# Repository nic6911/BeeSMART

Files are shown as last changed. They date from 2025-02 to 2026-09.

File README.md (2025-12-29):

# BeeSMART

If you like then please

"Buy Me A Coffee" (https://bmc.link/nic6911w)

This work is licensed under a  
[Creative Commons Attribution-NonCommercial-ShareAlike 4.0 International License][cc-by-nc-sa].

[][cc-by-nc-sa]

[cc-by-nc-sa]: http://creativecommons.org/licenses/by-nc-sa/4.0/  
[cc-by-nc-sa-image]: https://licensebuttons.net/l/by-nc-sa/4.0/88x31.png  
[cc-by-nc-sa-shield]: https://img.shields.io/badge/License-CC%20BY--NC--SA%204.0-lightgrey.svg

---

## Buy one, Køb en, Kaufen 
€200 + shipping from DK

Write me an email:

Contact

---

## What is it?
Honey filling system controlled from your phone, tablet or PC !

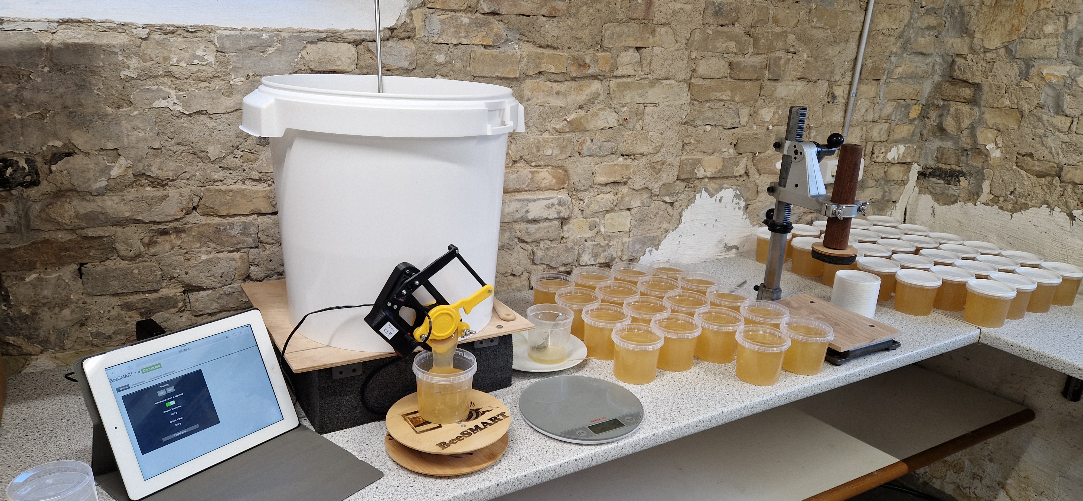
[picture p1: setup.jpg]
Setup
 

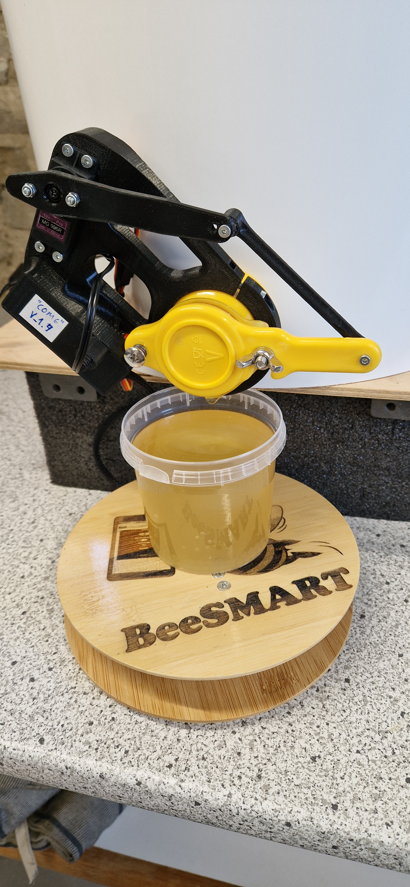
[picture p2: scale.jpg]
Scale
 

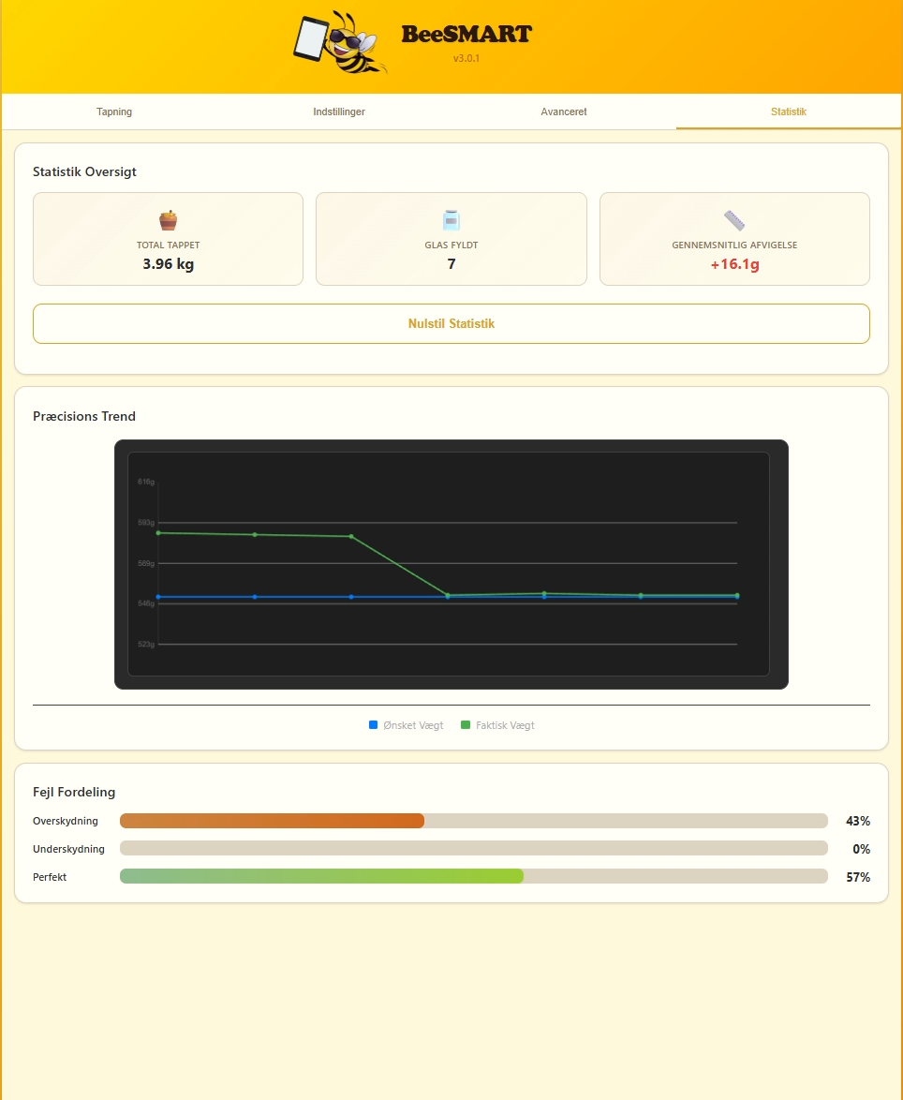
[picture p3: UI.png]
 

---

## Dansk
Honning tappemaskine til den lille produktion.
WIFI baseret med brugerinterface på pc, tablet eller smartphone uden en app.

### Video
Demo: https://youtu.be/7Y-k81tILdg
Montage: https://youtu.be/ojsv-gZ6waY

### Specs
Leverer inden for +/- 5g. Doseringsmængden kan indstilles mellem 50g og 20kg (Vær opmærksom på vægtens max belastning som kan være væsentligt mindre end 20kg !).
Se manual for funktionalitet: https://github.com/nic6911/BeeSMART/blob/develop/Documentation/manualDK.pdf

--- 

## Deutsch
Honig Abfüllsystem für den kleinen Produktion.
BeeSMART basiert sich auf WiFi und bietet eine Benutzeroberfläche 
entweder auf einem PC, Tablet oder Smartphone, ohne dass eine APP benötigt wird.

### Video
Demo: https://youtu.be/7Y-k81tILdg
Montage: https://youtu.be/ojsv-gZ6waY

### Specs
Es ist möglich mit einer Genauigkeit von +/- 5g zu erreichen. Der Menge kann zwischen 50g und 20kg eingestellt werden (Achte auf die maximale Belastung der Waage, die möglicherweise deutlich weniger als 20 kg beträgt !).
Für detaillierte Beschreibung von Funktionalität bitte lesen sie das Manual hier: https://github.com/nic6911/BeeSMART/blob/develop/Documentation/manualDE.pdf

---

## English
Honey filling machine for the small production.
WIFI based with user interface on pc, tablet or smartphone without the need for an app.

### Video
Demo: https://youtu.be/7Y-k81tILdg
Assembly: https://youtu.be/ojsv-gZ6waY

### Specs
An accuracy of +/- 5g is achievable. The amount to fill can be selected in the range from 50g to 20kg (Be mindful of the scale's maximum load, which may be significantly less than 20kg !).
See the user manual for more information: https://github.com/nic6911/BeeSMART/blob/develop/Documentation/manualEN.pdf

---

## Mechanical parts
Find the STL files for 3D printing in the STL's folder. The 2nd revision fits the updated hardware that is also found in the hardware folder.

## Hardware
The hardware is specifically designed for the project. RJ45 is utilized for connecting scale and mainboard, giving a seamless and robust connection. Power is provided from a 3A 5V USB-C power supply while the servo has its dedicated connector on the main board.
Schematic drawings, production files and source files are found under each subsystem folder in the Hardware folder (i.e. Scale and Mainboard).

### Mainboard
The mainboard contains the ESP32C3 and interfaces for programmin and power (USB-C), scale and servo as well as reset and boot buttons. The system is easily programmed using Arduino through the USB-C interface.

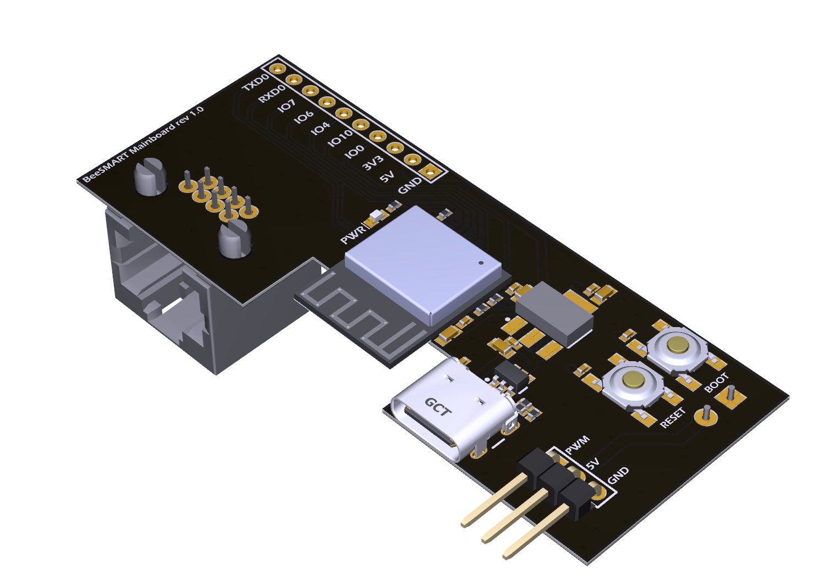
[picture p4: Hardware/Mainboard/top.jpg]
 

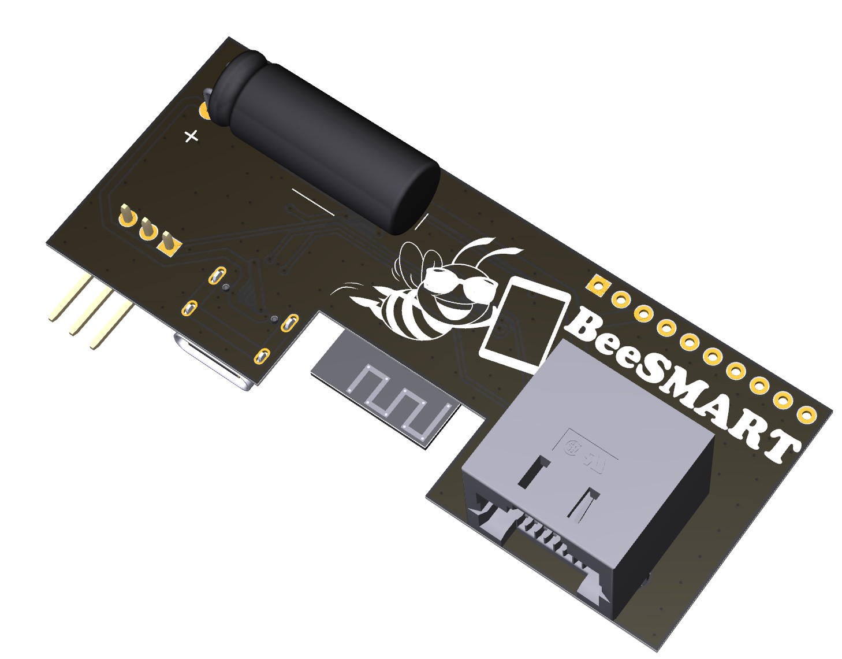
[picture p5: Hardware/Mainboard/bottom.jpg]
 

### Scale
The scale board contains an HX711 to interface with common load cells. No programming required - but calibration from the main controller is required at commissioning.

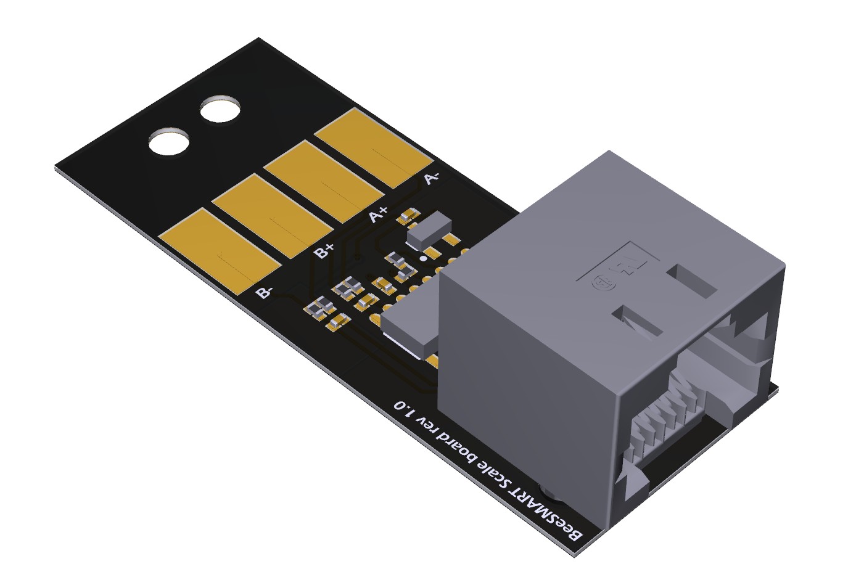
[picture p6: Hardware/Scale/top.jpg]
 

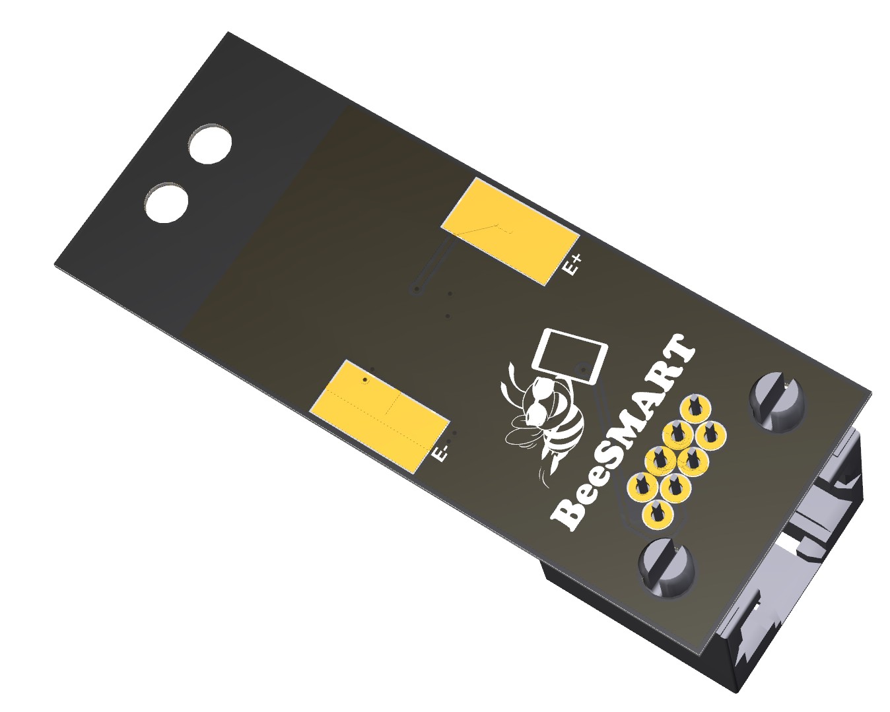
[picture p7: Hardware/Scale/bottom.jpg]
 

## Construction
There are a number of parts to acquire and some to 3D print. All the parts for printing are found in the Mechanical folder. You'll need one of each BUT only one of the brackets (either 40 or 53mm) and one of the main controller housing (40 or 53mm).

Besides the 3D printed parts some of the main components you'll need are:

- 2 x Ikea Bamboo lids Art no 103.819.09
- 1 x Standard size servo like e.g., MG996R
- 1 x Load cell
- 1 x Mainboard
- 1 x Scale board
- 1 x 5V 3A USB-C power supply
- 1 x RJ45 cable

The scale is constructed using two Ikea Bamboo lids Art no 103.819.09, the 3D printed encapsulation, electronics and a load cell that can be found almost anywhere. To assemble the scale, two holes must be drilled in each bamboo lid, where one side of the load cell is typically M4 and the other side M5. To mount them you'll need 2 x M4x25 and 2 x M5x30.

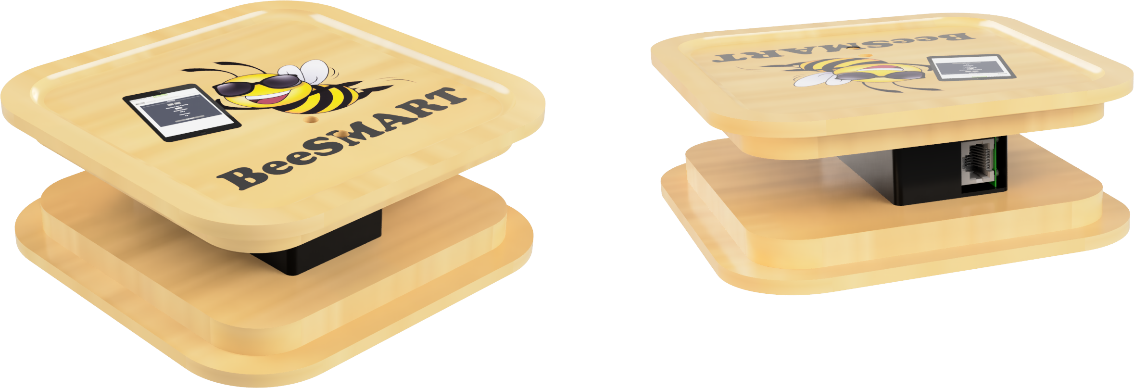
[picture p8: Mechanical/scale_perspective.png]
 

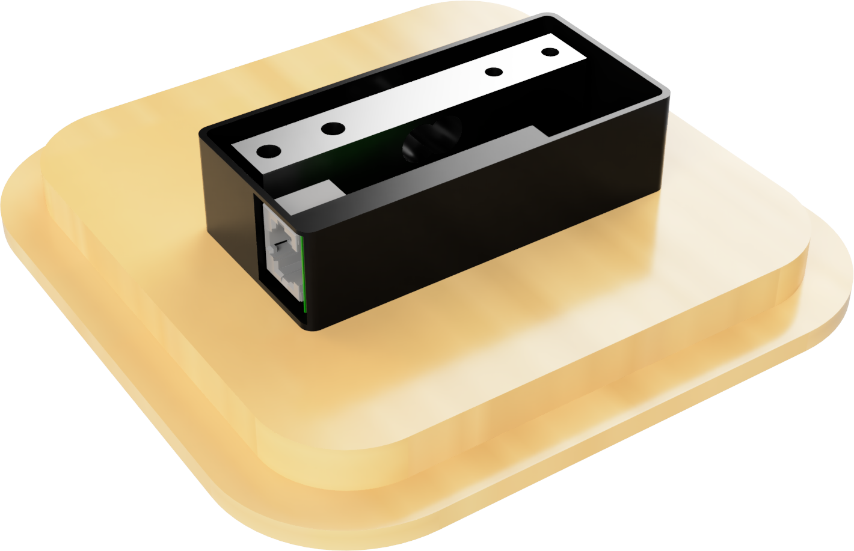
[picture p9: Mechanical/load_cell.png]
 

The "controller" is the unit that contains the Mainboard and Servo. The servo is a standard size servo like the MG996R. To mount that in the 3D printed housing you'll need 4 x M3x25 and 4 x M3 nuts.

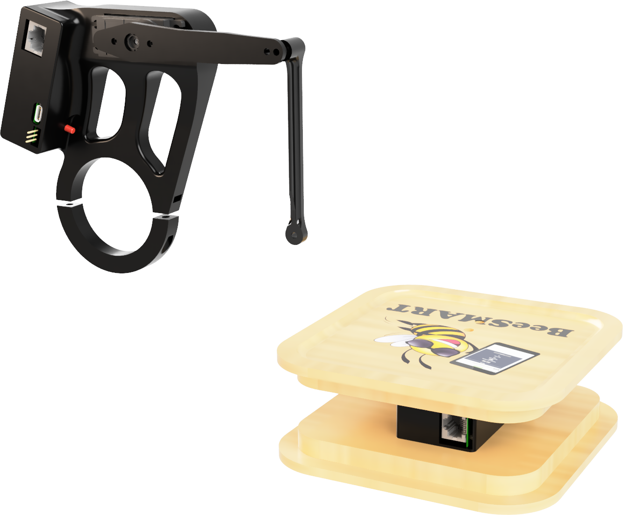
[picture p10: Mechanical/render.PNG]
 

All the remaining screws and nuts required are listed on the BOM in the manual.

## Software
The software is not prettified but has the functionality needed. It utilizes existing libraries to provide and host the UI. Scale calibration is incorporated in the software, making it easy commission a new system. Find the latest software in the software folder.

### HiL
The HiL folder contains a hardware-in-loop software package. I have updated it to make it relatively plug & play - simply just upload the BeeSMART software to one board and the "combinedsimulator" to another and connect scale and servo pins 1:1. This now gives you a superb opportunity for tuning the software on different simulated viscosities as a semi-advanced model has been implemented for simulating the behavior of the bucket and honey.
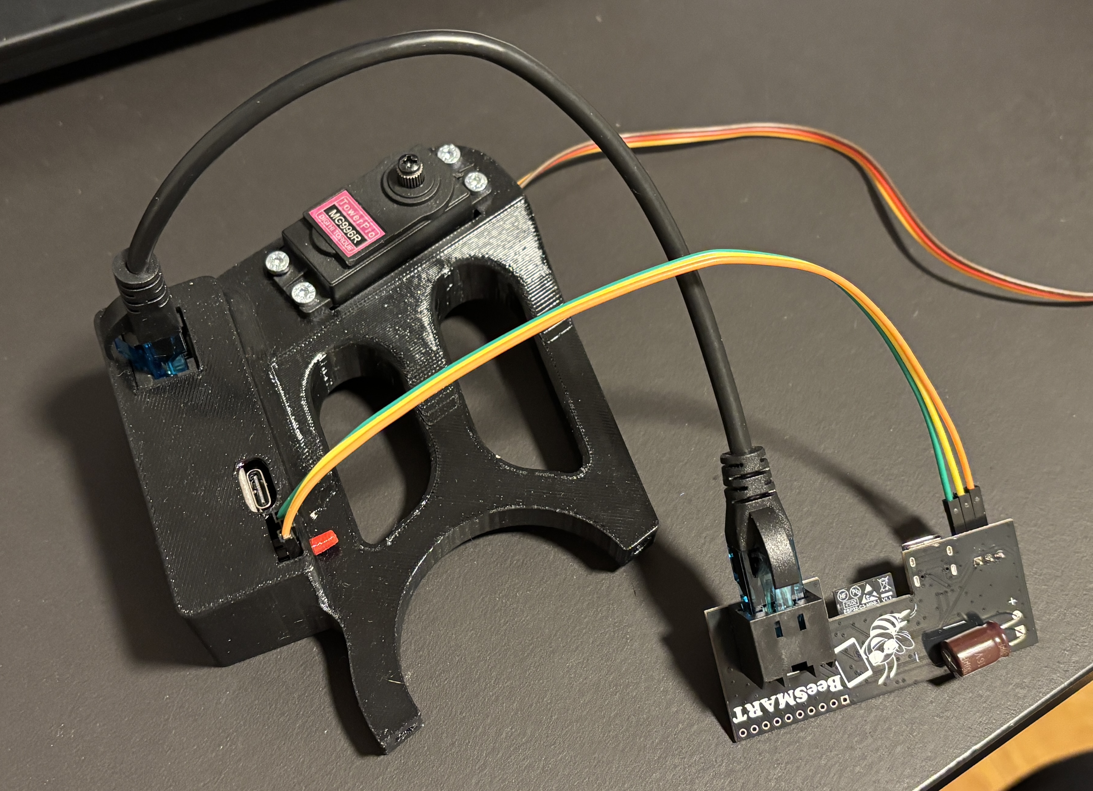
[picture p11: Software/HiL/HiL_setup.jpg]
 
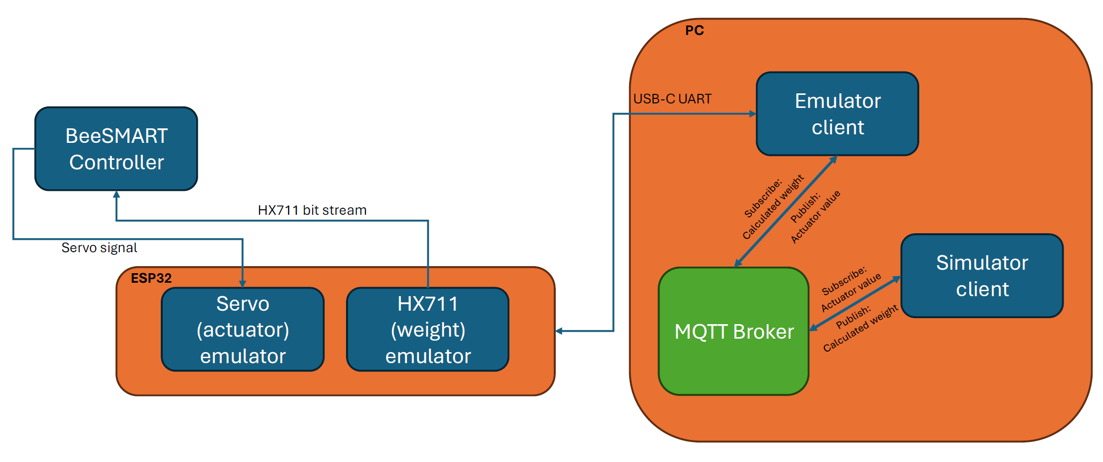
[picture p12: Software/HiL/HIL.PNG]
 

---

## Disclaimer

**Use at your own risk!** Improper connections could potentially damage hardware. The hardware and software have been tested with the listed devices without issues.

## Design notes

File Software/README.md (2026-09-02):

# BeeSMART honeyDosing — Build & Upload Instructions (v3.3.0)

## Prerequisites

| Tool | Version | Notes |
|---|---|---|
| [Arduino CLI](https://arduino.github.io/arduino-cli/) | ≥ 1.2.x | Or Arduino IDE 2.x |
| ESP32 board package | `esp32:esp32` ≥ 3.3.x | Install via board manager |
| [mklittlefs](https://github.com/earlephilhower/mklittlefs) | Bundled with ESP32 package | Used to build the filesystem image |

### Arduino Libraries

Install via the Arduino Library Manager or `arduino-cli lib install`:

| Library | Version |
|---|---|
| ArduinoJson | ≥ 7.4.x |
| ESP32Servo | ≥ 3.1.x |
| HX711 | ≥ 0.6.x |
| ArduPID | **0.2.1** (do NOT use 1.0.x — incompatible API) |

> **ESPmDNS** is part of the ESP32 board package and does not need a separate install.

## Hardware

- **Board:** ESP32-C3 (e.g. ESP32-C3-WROOM-02)
- **Connection:** USB-Serial/JTAG (native USB on the C3)
- **COM port:** Check Device Manager — the device appears as "USB JTAG/serial debug unit"

## Building the Firmware

### Using Arduino CLI

```bash
# Install ESP32 board support (first time only)
arduino-cli core install esp32:esp32

# Install required libraries (first time only)
arduino-cli lib install ArduinoJson@7.4.3 ESP32Servo@3.1.3 HX711@0.6.3 ArduPID@0.2.1

# Compile
arduino-cli compile --fqbn esp32:esp32:esp32c3:CDCOnBoot=cdc honeyDosing_v3/
```

### Using Arduino IDE

1. Open `honeyDosing_v3/honeyDosing_v3.ino`
2. Select board: **ESP32C3 Dev Module**
3. Set **USB CDC On Boot: Enabled**
4. Click **Verify/Compile**

## Building the Filesystem Image

Run `build_merge.bat` to create the LittleFS image containing the web UI:

```
.\build_merge.bat
```

This creates `build/littlefs.bin` (1.38 MB).

## Uploading

### Firmware

```bash
# Via arduino-cli
arduino-cli upload --fqbn esp32:esp32:esp32c3:CDCOnBoot=cdc -p COM15 honeyDosing_v3/
```

Replace `COM15` (or `/dev/ttyACM0` on Linux) with your actual port.

### Filesystem (Web UI)

Flash the LittleFS image at offset `0x290000`:

```bash
# Via esptool
esptool.py --chip esp32c3 -p COM15 write-flash 0x290000 build/littlefs.bin
```

> **Tip:** After uploading both, connect to the **BeeSMART** Wi-Fi network and navigate to `beesmart.local` (or `192.168.4.1`) in a browser.

## Project Structure

```
honeyDosing_v3/
├── honeyDosing_v3.ino    # Entry point (setup + loop only)
├── src/                   # Modular firmware source
│   ├── config.h           # Constants, pins, structs
│   ├── globals.h/.cpp     # Global variables + language strings
│   ├── filesystem.h/.cpp  # File I/O, settings persistence
│   ├── statistics.h/.cpp  # Dispensing records, weight sampling
│   ├── control.h/.cpp     # PID, state machines (dosing/calibration)
│   └── webserver.h/.cpp   # HTTP API, WebSocket, captive portal
├── data/                  # Web UI assets (uploaded as LittleFS)
│   ├── index.html
│   ├── app.js
│   ├── styles.css
│   └── beesmart_bee.webp  # 62KB logo (was 521KB PNG)
├── build_merge.bat        # LittleFS image builder (Windows)
├── CHANGELOG.md           # Version history
└── README.md              # This file
```

## Troubleshooting

- **Upload fails / no COM port:** Ensure the ESP32-C3 is connected via its native USB port. Hold the BOOT button while pressing RESET to enter download mode if needed.
- **Web UI not loading after firmware upload:** Make sure you also flashed the LittleFS filesystem image at `0x290000`.
- **ArduPID compile errors:** Verify you have version **0.2.1**, not 1.0.x. The API changed significantly between versions.

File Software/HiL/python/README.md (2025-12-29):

# Honey Dispenser Model Documentation

## Overview

This repository contains a physics-based simulation of a honey dispensing system, designed for Hardware-in-the-Loop (HiL) testing. The model simulates a bucket of honey with a servo-controlled tap, and calculates the flow rate, transport delay, and dispensed weight based on actuator input and physical parameters. The system is integrated with MQTT for real-time control and state monitoring.

---

## `model.py` — HoneyDispenserModel

### Purpose
A class-based model that simulates the dispensing of honey from a bucket through a tap, considering geometry, viscosity, temperature, actuator position, and transport delay.

### Parameters
- **Bucket diameter** ($d_{bucket}$, cm)
- **Bucket height** ($h_{bucket}$, cm)
- **Tap diameter** ($d_{tap}$, mm)
- **Tap-to-scale distance** ($L_{tap-scale}$, cm)
- **Initial fill height** ($h_{fill}$, cm)
- **Viscosity type** (low, medium, high)
- **Temperature** ($T$, °C)

### Key Equations & Reasoning

#### 1. **Viscosity Adjustment**
Viscosity ($\eta$) is temperature-dependent:

η = η₀ · 2^((20 − T) / 10)

Where $\eta_0$ is the base viscosity for the selected honey type.

#### 2. **Bucket Head Pressure**
Pressure at the tap due to honey column:

P = ρ · g · h_fill

Where:
- $\rho$ = honey density ($\approx 1400\,kg/m^3$)
- $g$ = gravity ($9.81\,m/s^2$)
- $h_{fill}$ = current honey height (m)

#### 3. **Tap Area**

A_tap = π · (d_tap / 20)²

Where $d_{tap}$ is in mm, converted to cm.

#### 4. **Flow Rate (Hagen-Poiseuille Law, simplified)**

Q = (π · r⁴ · ΔP) / (8 · η · L)

Where:
- $r$ = tap radius (m)
- $\Delta P$ = pressure difference (Pa)
- $\eta$ = viscosity (Pa·s)
- $L$ = tap length ($\approx d_{tap}$, m)

Converted to grams/second:

Q_g/s = Q_m³/s · ρ · 1000

#### 5. **Transport Delay**
Time for honey to reach the scale:

delay = L_tap-scale / v

Where $v$ is average velocity:

v = Q_kg/s / (ρ · A_tap)

#### 6. **Bucket Fill Update**
After each simulation step:

Δh_fill = (Q_g/s · dt) / (ρ · A_bucket · 10)

Where $A_{bucket}$ is the bucket cross-sectional area (cm²).

### Usage Example
```python
from model import HoneyDispenserModel
model = HoneyDispenserModel()
model.set_tap_opening(1.0)  # fully open
dispensed = model.step(1.0) # simulate 1 second
state = model.get_state()
```

---

## HiL System Integration (`model_handler.py` & `hilbee.py`)

### Purpose
`model_handler.py` launches the honey dispenser simulation, exposes a PyQt5 UI for manual and automatic jar placement, and manages MQTT communication. It also starts `hilbee.py` as a subprocess for serial/MQTT integration.

### Features
- PyQt5 UI for manual jar placement ("Place jar" and "Remove jar" buttons)
- Dropdown menu to select available COM ports
- "Connect" button to start the system with the selected port (turns to "Disconnect" when running)
- "Disconnect" button stops the system and terminates `hilbee.py`
- Slider for enabling/disabling automatic jar placement
- Auto jar placement: When enabled, waits 10 seconds after the tap is closed, removes the jar, waits 2 seconds, places the jar, and repeats until the bucket is nearly empty (`fill_height_cm < 2`)
- Listens for actuator values on MQTT (`actuator` topic)
- Publishes model state as JSON to the `state` topic
- Publishes total dispensed weight for legacy compatibility (`weight` topic)
- Starts and terminates `hilbee.py` automatically with the selected port

### System Architecture
```
[Serial/Hardware] <-> [hilbee.py] <-> [MQTT Broker] <-> [model_handler.py + PyQt5 UI] <-> [HoneyDispenserModel]
```
- **Actuator input**: Received via MQTT or serial, mapped to tap opening (0-100%)
- **Model simulation**: Calculates flow, delay, and dispensed weight
- **State output**: All model states published as JSON on MQTT for downstream use

### Example State Output (MQTT `state` topic)
```json
{
  "fill_height_cm": 59.8,
  "tap_opening": 1.0,
  "temperature_c": 30.0,
  "viscosity_type": "low",
  "viscosity_Pa_s": 1.0,
  "flow_g_per_s": 120.5,
  "transport_delay_s": 0.8,
  "total_dispensed_g": 240.0
}
```

### Usage
1. Install dependencies from `requirements.txt` (see below for PyQt5 and other requirements).
2. Activate your Python virtual environment.
3. Run `model_handler.py`.
4. In the PyQt5 UI, select the desired COM port from the dropdown and press "Connect" to start the system (this will start `hilbee.py` with the selected port).
5. Use the UI to manually place/remove the jar, or enable auto jar placement.
6. Press "Disconnect" to stop the system and terminate `hilbee.py`.
7. The simulation will run until the bucket is nearly empty.

#### Requirements
- Python 3.x
- PyQt5
- paho-mqtt
- pyserial
- keyboard

Install with:
```sh
pip install -r requirements.txt
```

---

## Reasoning & Extensibility
- The model is designed for realism and configurability, allowing HiL testing with different honey types, temperatures, and hardware setups.
- All physical parameters are exposed and can be tuned for your scenario.
- MQTT integration enables seamless connection to real or simulated hardware and control systems.
- The PyQt5 UI makes it easy to control and automate jar placement for testing and demonstration purposes.

---

## References
- [Hagen-Poiseuille Law](https://en.wikipedia.org/wiki/Hagen%E2%80%93Poiseuille_equation)
- [Honey Viscosity Data](https://www.sciencedirect.com/science/article/pii/S0023643819303932)

---

## License
This work is licensed under a  
[Creative Commons Attribution-NonCommercial-ShareAlike 4.0 International License][cc-by-nc-sa].

[][cc-by-nc-sa]

[cc-by-nc-sa]: http://creativecommons.org/licenses/by-nc-sa/4.0/  
[cc-by-nc-sa-image]: https://licensebuttons.net/l/by-nc-sa/4.0/88x31.png  
[cc-by-nc-sa-shield]: https://img.shields.io/badge/License-CC%20BY--NC--SA%204.0-lightgrey.svg

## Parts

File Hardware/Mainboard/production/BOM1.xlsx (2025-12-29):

Comment | Designator | Footprint | LCSC Part Number
100nF 0402 | C1, C4, C14, C20, C21, C22 | CAP_0402 | C1525
3V3 LDO | U1 | LDO | C6186
RJ45 | PL2 | RJ45 | C385834
68pF 0402 50V | C19 | CAP_0402 | C14441
22uF | C2, C3, C10, C13 | CAP_0603 | C59461
LED Green | D3 | 0603 LED | C165982
10k | R9, R13, R14 | RES_0402 | C25744
SRV05 | U5 | SOT95P280X145 | C85364
USB-C | J1 | KH-TYPE-C-16P | C709357
ESP32-C3-MINI-1-N4 | U6 | ESP32-C3-MINI-1-N4-Footprint-1 | C2838502
1M 0402 | R22 | RES_0402 | C26083
4k7 0402 | R2, R20, R21 | RES_0402 | C25900
TACTB-64K-F | S1, S2 | TACTB-64K-F | C318884
2.54 3-pin angle | PL3 | 3-pin angle | C92159

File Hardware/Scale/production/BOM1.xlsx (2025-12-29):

Comment | Designator | Footprint | LCSC Part Number
100nF 0402 | C3, C4, C5 | CAP_0402 | C1525
8k2 0402 | R2, R3 | RES_0402 | C25924
10uF 0402 6V3 | C1, C2 | CAP_0402 | C76991
LED green | D3 | 0603 LED | C165982
HX711 | U1 | HX711 | C6705483
PNP S8550 | Q1 | SOT23 | C105432
RJ45 | PL2 | RJ45 | C385834
100R | R4, R5, R6, R7 | RES_0402 | C25076
22k | R1 | RES_0402 | C25768

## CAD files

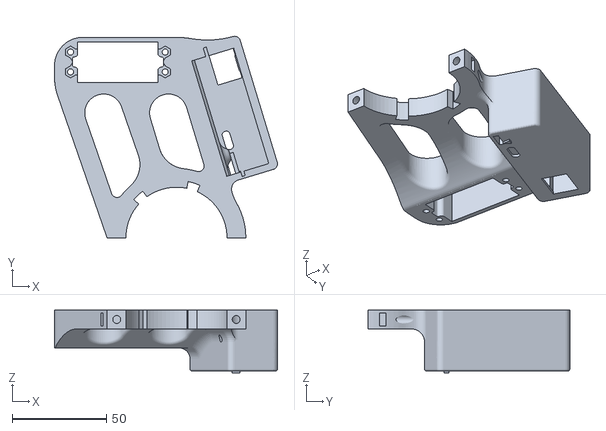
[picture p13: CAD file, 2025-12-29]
Mechanical/rev3 main.stl
118.0 x 106.7 x 33.3

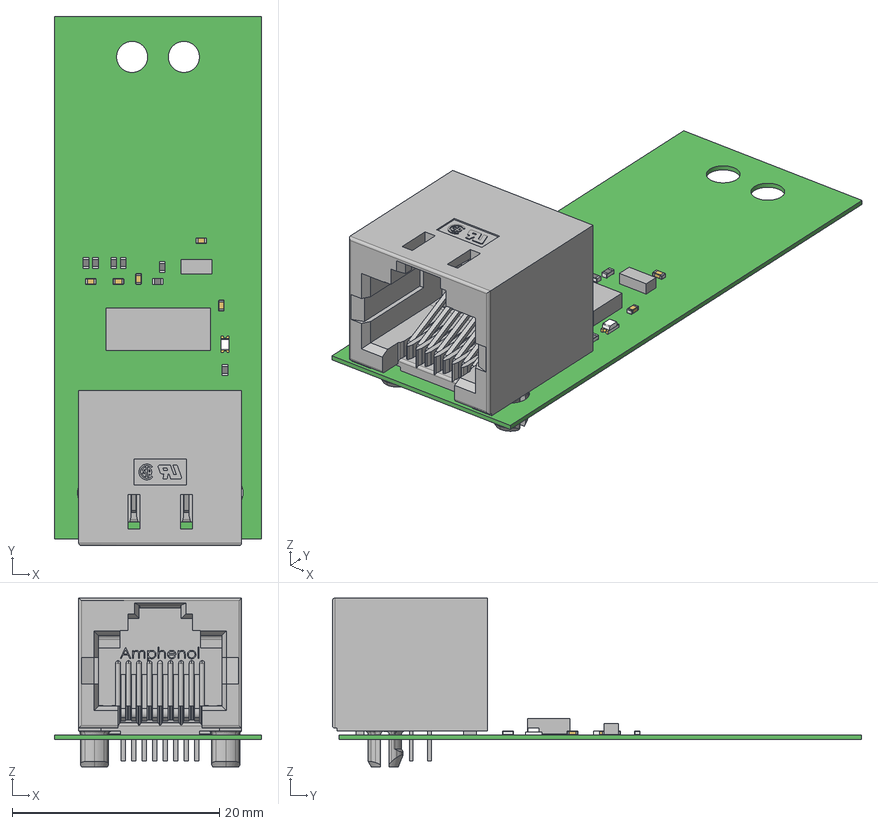
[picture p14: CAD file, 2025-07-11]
Hardware/Scale/beesmart_scale.step
20.0 x 51.1 x 16.3 mm
Mid_Body x 7
Open_CASCADE_STEP_translator_6.8_6.2.1 x 14
Mark x 7
LED_0603_single_color
Open_CASCADE_STEP_translator_6.8_7.1.1 x 5
Open_CASCADE_STEP_translator_6.8_7.1.2 x 5
Open_CASCADE_STEP_translator_6.8_7.2.1 x 5
Extruded x 2
M-RJHSE-5080-REVT1_RGB8421504

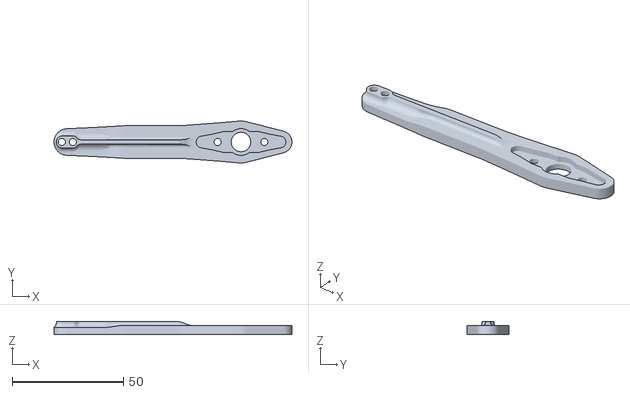
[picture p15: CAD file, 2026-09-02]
Mechanical/Servo_arm.stl
106.9 x 18.9 x 5.75

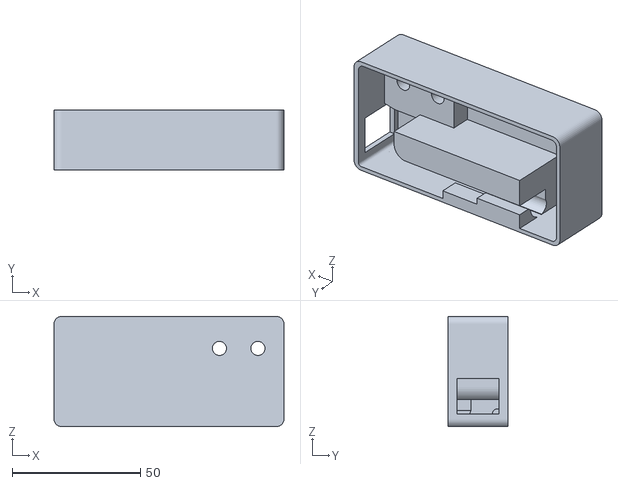
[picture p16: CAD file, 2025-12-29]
Mechanical/scale_rev3.stl
89.7 x 23.5 x 43.0

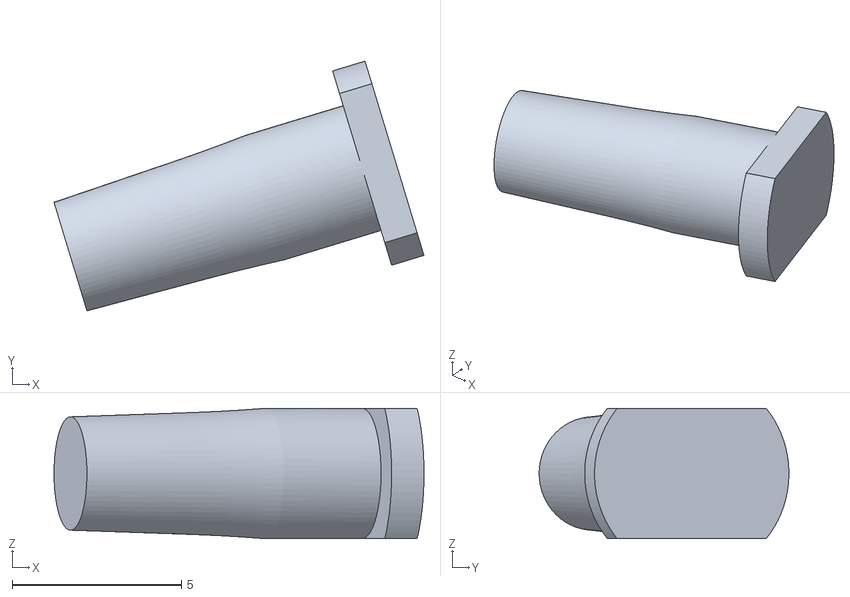
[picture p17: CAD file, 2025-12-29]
Mechanical/Reset rev3.stl
10.9 x 7.38 x 3.85

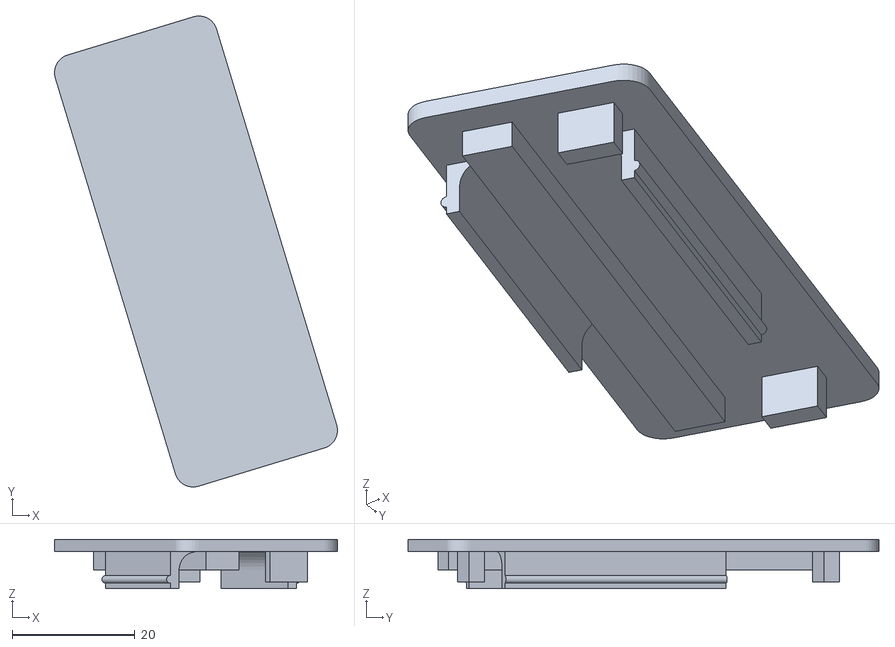
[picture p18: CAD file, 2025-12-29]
Mechanical/Lid rev3.stl
46.2 x 76.8 x 8.00

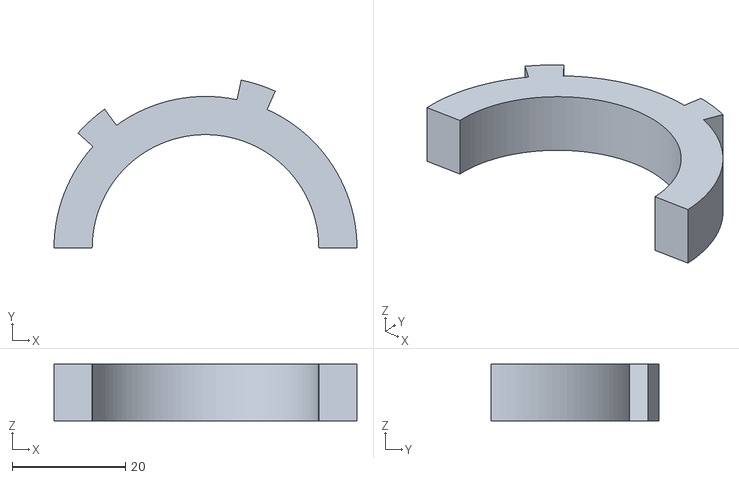
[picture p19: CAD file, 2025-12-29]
Mechanical/40mm top insert.stl
53.5 x 29.6 x 10.0

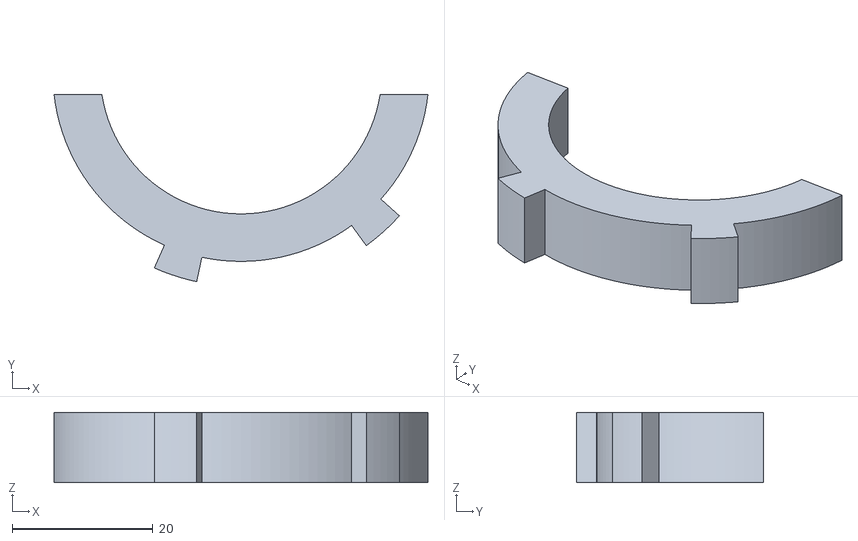
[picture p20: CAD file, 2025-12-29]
Mechanical/40mm btm insert.stl
53.2 x 26.6 x 10.0

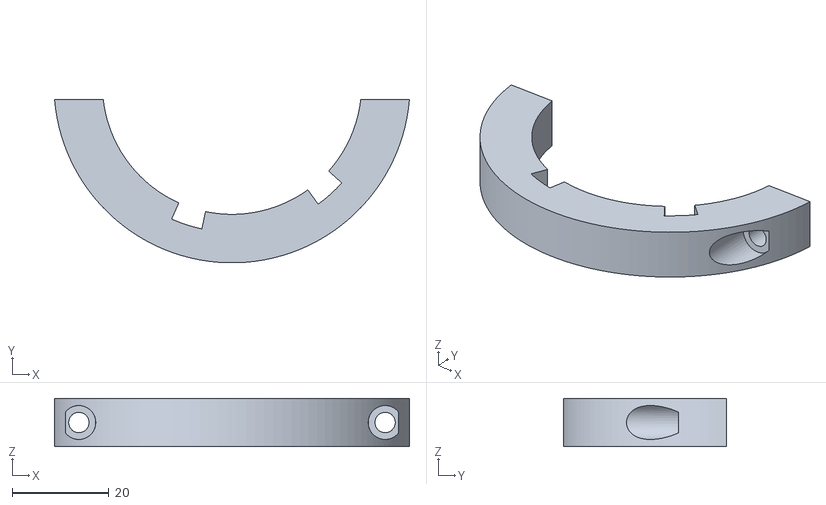
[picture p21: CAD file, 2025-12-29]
Mechanical/53mm btm bracket.stl
73.3 x 33.7 x 10.0

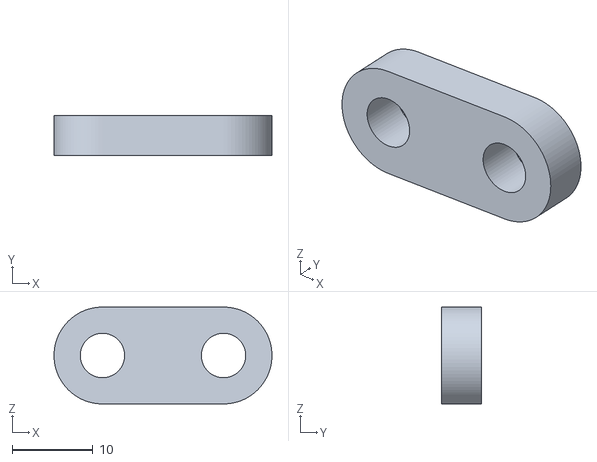
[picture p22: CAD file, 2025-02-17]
Mechanical/scale_spacer.stl
27.0 x 5.00 x 12.0

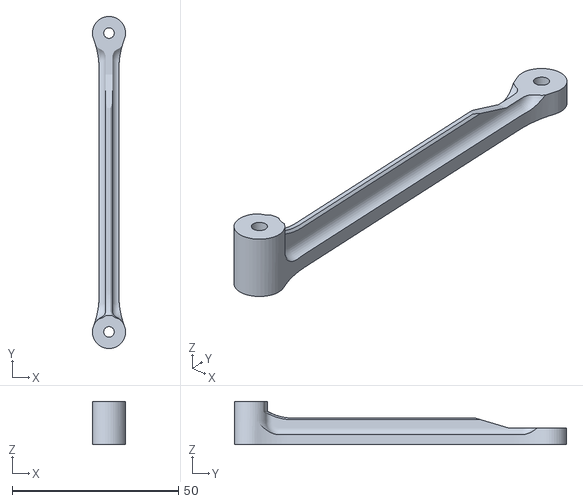
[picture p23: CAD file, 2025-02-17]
Mechanical/Linkarm.stl
9.98 x 100.0 x 13.0

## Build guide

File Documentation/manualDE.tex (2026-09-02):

% ======================================================================
% BeeSMART Handbuch (Für den Druck optimierte LaTeX-Version)
% Stil B — Sauber, professionell, BeeSMART Farbpalette + Schriftarten
% ======================================================================

\documentclass[11pt,a4paper]{article}

% ---------------------------------------------------------
% Packages
% ---------------------------------------------------------
\usepackage{fontspec}
\usepackage{titlesec}
\usepackage{graphicx}
\usepackage{geometry}
\usepackage{setspace}
\usepackage{hyperref}
\usepackage{xcolor}
\usepackage{tocloft}
\usepackage{parskip}
\usepackage{fancyhdr}
\usepackage{enumitem}
\usepackage[ngerman]{babel}
\usepackage[table]{xcolor}
\usepackage{qrcode}

% ---------------------------------------------------------
% Page Setup
% ---------------------------------------------------------
\geometry{
    a4paper,
    margin=2.2cm
}

\setstretch{1.25}

% ---------------------------------------------------------
% BeeSMART Color Palette (übersetzt aus CSS)
% ---------------------------------------------------------
\definecolor{primary}{HTML}{DAA520}        % Golden Rod
\definecolor{primarylight}{HTML}{F4D03F}   % Helles Gold
\definecolor{primarydark}{HTML}{B7950B}    % Dunkles Gold
\definecolor{secondary}{HTML}{FF8C00}      % Dunkles Orange
\definecolor{accent}{HTML}{FFE135}         % Leuchtendes Gelb
\definecolor{success}{HTML}{8FBC8F}        % Gedämpftes Grün
\definecolor{destructive}{HTML}{CD853F}    % Peru
\definecolor{warning}{HTML}{F0E68C}        % Khaki
\definecolor{textprimary}{HTML}{2F2F2F}    % Dunkelgrau
\definecolor{textsecondary}{HTML}{8B7355}  % Warmes Braun-Grau
\definecolor{separator}{HTML}{DDD3C0}      % Beige

% ---------------------------------------------------------
% Fonts (Cooper Black + Fredoka One)
% ---------------------------------------------------------
\setmainfont{Segoe UI}[
    Ligatures=TeX
]

\newfontfamily\cooper{Cooper Black}
\newfontfamily\fredoka{Fredoka One}

% ---------------------------------------------------------
% Heading Styles
% ---------------------------------------------------------
\titleformat{\section}
  {\large\bfseries\cooper\color{primarydark}}
  {\thesection}{1em}{}

\titleformat{\subsection}
  {\normalsize\bfseries\fredoka\color{secondary}}
  {\thesubsection}{1em}{}

\titleformat{\subsubsection}
  {\normalsize\bfseries\color{textprimary}}
  {\thesubsubsection}{1em}{}

% ---------------------------------------------------------
% Table of Contents Styling
% ---------------------------------------------------------
\renewcommand{\cftsecleader}{\cftdotfill{\cftdotsep}}

% ---------------------------------------------------------
% Hyperlink Colors
% ---------------------------------------------------------
\hypersetup{
    colorlinks=true,
    linkcolor=primarydark,
    urlcolor=secondary
}

% ---------------------------------------------------------
% Headers and Footers
% ---------------------------------------------------------
\pagestyle{fancy}
\fancyhf{} % clear all
\lhead{\textcolor{textsecondary}{BeeSMART Handbuch}}
\rhead{\textcolor{textsecondary}{\leftmark}}
\cfoot{\textcolor{textsecondary}{\thepage}}
\renewcommand{\headrulewidth}{0.4pt}
\renewcommand{\headrule}{\hbox to\headwidth{\color{separator}\leaders\hrule height \headrulewidth\hfill}}
\renewcommand{\footrulewidth}{0pt}

% ---------------------------------------------------------
% Document Start
% ---------------------------------------------------------
\begin{document}

% ---------------------------------------------------------
% Cover Page
% ---------------------------------------------------------
\begin{titlepage}
    \centering
    {\cooper\fontsize{28}{32}\selectfont BeeSMART Handbuch}\\[1.5em]
    {\fredoka\Large Wi-Fi gesteuerte Zapf-/Füllmaschine}\\[1em]
    {\large Version 3.0}\\[3em]

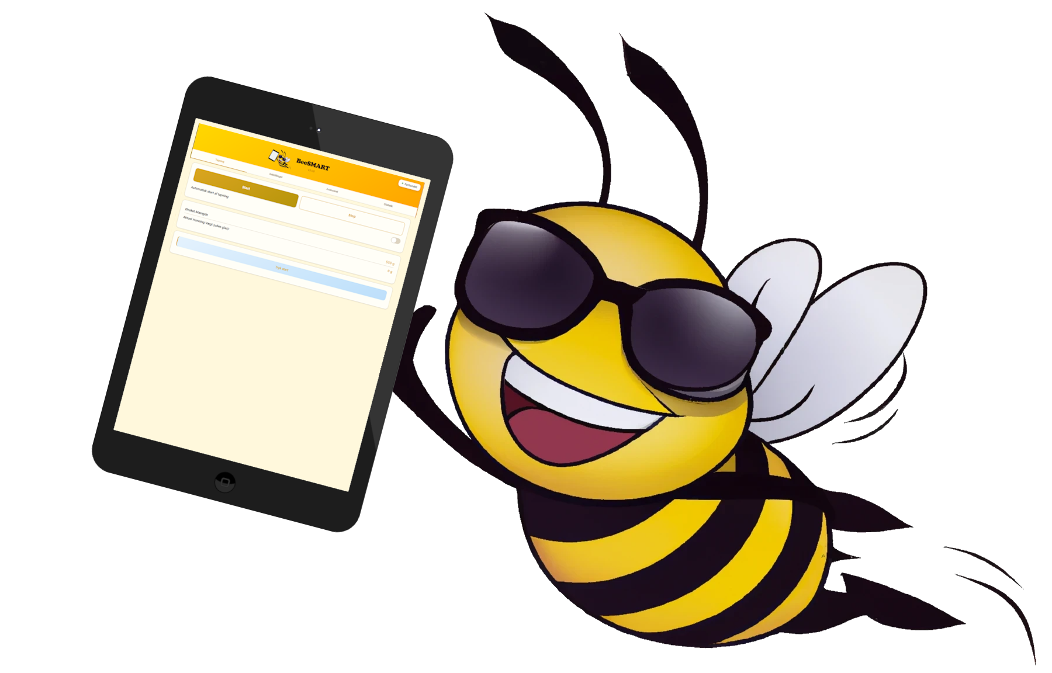
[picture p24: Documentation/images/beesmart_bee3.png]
    \\[3em]

    {\small Entwickelt von Mogens Groth Nicolaisen}\\
    {\small Zuletzt aktualisiert: Juni 2026}

\end{titlepage}

\newpage

% ---------------------------------------------------------
% Table of Contents
% ---------------------------------------------------------
\tableofcontents
\newpage

% ---------------------------------------------------------
% 1. Einführung
% ---------------------------------------------------------
\section{Einführung}

BeeSMART ist ein Wi‑Fi‑basiertes Zapfsystem für Honig mit Fokus auf wenige Komponenten, einfache Bedienung und relativ niedrigen Kosten. Das System kann selbstverständlich auch für andere Flüssigkeiten verwendet werden, bei denen gewichtsbasiertes Befüllen gewünscht ist.

Das System ist browserbasiert und erfordert keine App. Sie greifen über PC, Tablet oder Smartphone darauf zu, sofern das Gerät mit dem BeeSMART‑Wi‑Fi verbunden ist.

\begin{center}
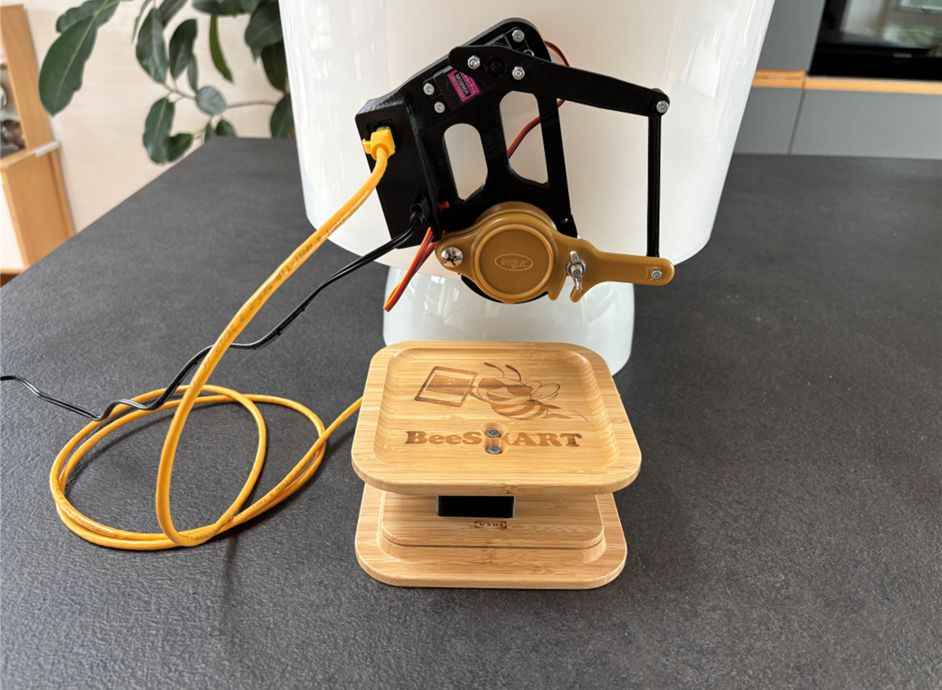
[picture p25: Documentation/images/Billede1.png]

\end{center}

Das System besteht typischerweise aus:
\begin{itemize}[leftmargin=*]
    \item BeeSMART Modul mit integrierter Wi‑Fi‑Steuerung und Servo
    \item Servo‑Horn und Zugstange
    \item BeeSMART Waage (5 kg)
    \item USB‑C Netzteil
    \item Montagehalterung und Einsätze für verschiedene Zapfhähne
\end{itemize}

Die Montagehalterung passt für Zapfhähne mit einem Kragen von ca. 54 mm Durchmesser und mindestens 10 mm Breite. Einsätze für 40 mm Kragen werden mitgeliefert.

\newpage

% ---------------------------------------------------------
% 2. Stückliste
% ---------------------------------------------------------
\section{Stückliste}

\begin{center}
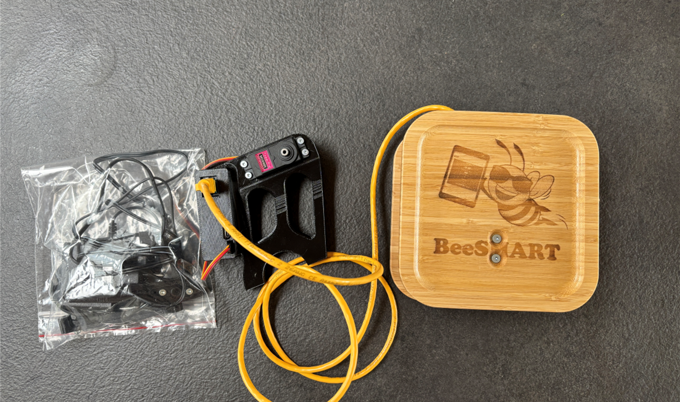
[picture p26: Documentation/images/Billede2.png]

\end{center}

Standardinhalt eines BeeSMART‑Sets:

\begin{center}
    \renewcommand{\arraystretch}{1.3}
    
    \begin{tabular}{ll}
        \rowcolor{primarylight!40}
        {\fredoka\textbf{Anzahl}} & {\fredoka\textbf{Komponente}} \\
        
        \rowcolor{primarylight!15}
        2 × & M3 selbstsichernde Mutter \\
        
        \rowcolor{primarylight!5}
        2 × & M4 Mutter \\
        
        \rowcolor{primarylight!15}
        1 × & M3 × 16 Schraube \\
        
        \rowcolor{primarylight!5}
        1 × & M3 × 25 Schraube \\
        
        \rowcolor{primarylight!15}
        2 × & M4 × 25 Schraube \\
        
        \rowcolor{primarylight!5}
        1 × & BeeSMART Modul mit Servo und Wi‑Fi‑Steuerung \\
        
        \rowcolor{primarylight!15}
        1 × & Zugstange \\
        
        \rowcolor{primarylight!5}
        1 × & Servo‑Horn, Verlängerung und Schraube \\
        
        \rowcolor{primarylight!15}
        2 × & Einsätze für 40 mm Zapfhahn \\
        
        \rowcolor{primarylight!5}
        1 × & 5 kg BeeSMART Waage \\
        
        \rowcolor{primarylight!15}
        1 × & USB‑C Netzteil \\
        
    \end{tabular}
\end{center}
\newpage

% ---------------------------------------------------------
% 3. Videomaterial
% ---------------------------------------------------------
\section{Videomaterial}

Zu BeeSMART gibt es Videomaterial mit:

\begin{itemize}[leftmargin=*]
    \item Montage und Befestigung von BeeSMART
    \item Demonstration der Zapffunktionen
    \item Anwendungsbeispiele mit verschiedenen Einstellungen
\end{itemize}

\vspace{2em}
Die Videos sind besonders nützlich bei der ersten Einrichtung und zur Feinabstimmung von Servo und Steuerparametern.
\vspace{2em}

\begin{center}
	\begin{tabular}{cc}
		
		% ------------------ Row 1, Col 1 ------------------
		\begin{minipage}{0.45\textwidth}
			\centering
			\qrcode[height=3.5cm]{https://youtu.be/7Y-k81tILdg}\\[0.3em]
			
			\href{https://youtu.be/7Y-k81tILdg}{%
				{\fredoka\color{primarydark}\Large Demo 1}%
			}\\[-0.2em]
			
			\href{https://youtu.be/7Y-k81tILdg}{%
				{\small BeeSMART in Betrieb}%
			}
		\end{minipage}
		&
		% ------------------ Row 1, Col 2 ------------------
		\begin{minipage}{0.45\textwidth}
			\centering
			\qrcode[height=3.5cm]{https://youtube.com/shorts/xE0CEP3kYTg}\\[0.3em]
			
			\href{https://youtube.com/shorts/xE0CEP3kYTg}{%
				{\fredoka\color{primarydark}\Large Demo 2}%
			}\\[-0.2em]
			
			\href{https://youtube.com/shorts/xE0CEP3kYTg}{%
				{\small BeeSMART in Betrieb}%
			}
		\end{minipage}
		
		\\[8em]
		
		% ------------------ Row 2, Col 1 ------------------
		\begin{minipage}{0.45\textwidth}
			\centering
			\qrcode[height=3.5cm]{https://youtu.be/kUqcvOjCH5E}\\[0.3em]
			
			\href{https://youtu.be/kUqcvOjCH5E}{%
				{\fredoka\color{primarydark}\Large Demo 3}%
			}\\[-0.2em]
			
			\href{https://youtu.be/kUqcvOjCH5E}{%
				{\small Erweiterte Funktionen in 3.0}%
			}
		\end{minipage}
		&
		% ------------------ Row 2, Col 2 ------------------
		\begin{minipage}{0.45\textwidth}
			\centering
			\qrcode[height=3.5cm]{https://youtu.be/ojsv-gZ6waY}\\[0.3em]
			
			\href{https://youtu.be/ojsv-gZ6waY}{%
				{\fredoka\color{primarydark}\Large Montage}%
			}\\[-0.2em]
			
			\href{https://youtu.be/ojsv-gZ6waY}{%
				{\small Zapfhahn und Halterung}%
			}
		\end{minipage}
		
	\end{tabular}
\end{center}

\newpage

% ---------------------------------------------------------
% 4. Bedienungsanleitung
% ---------------------------------------------------------
\section{Bedienungsanleitung}

\subsection{Anschluss und Zugriff}

Nach Anschluss von USB‑Stromversorgung, Servo und Waage erstellt BeeSMART einen Wi‑Fi Access Point. Dies sollte innerhalb von ca. 30 Sekunden erfolgen. Falls nicht, drücken Sie kurz die Reset‑Taste am Modul.

\begin{center}
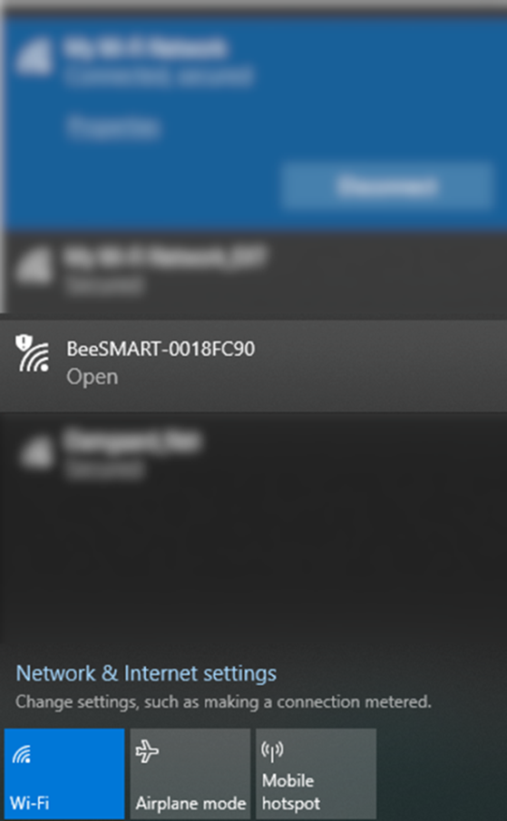
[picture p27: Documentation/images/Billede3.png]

\end{center}

Verbinden Sie sich mit dem angezeigten BeeSMART‑Netzwerk von PC, Tablet oder Smartphone. In vielen Fällen öffnet sich automatisch ein Browser mit der BeeSMART‑Benutzeroberfläche. Falls dies nicht geschieht, öffnen Sie den Browser manuell und geben folgende Adresse ein:

\begin{verbatim}
beesmart.local
\end{verbatim}

\noindent Alternativ kann auch die IP-Adresse \texttt{192.168.4.1} verwendet werden.

\subsection{Hauptbildschirm}

\begin{center}
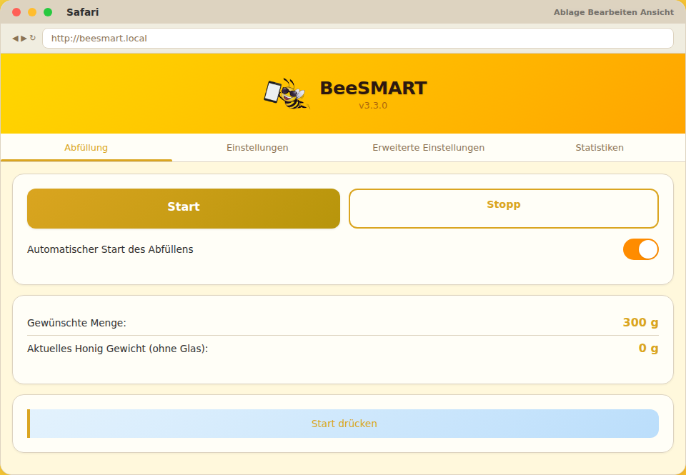
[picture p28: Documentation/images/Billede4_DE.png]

\end{center}

Der Hauptbildschirm bietet Übersicht über:

\begin{itemize}[leftmargin=*]
    \item Gewünschte Menge, die abgefüllt wird (ohne Glas)
    \item Aktuelles Gewicht auf der Waage
    \item Status‑Text unten, der beschreibt, was das System gerade macht
\end{itemize}

Die Schaltfläche \textbf{Start} startet einen Zapfvorgang, während \textbf{Stopp} einen laufenden Zapfvorgang unterbricht.

Die Funktion \textbf{Automatischer Start des Zapfens} kann über einen Schalter aktiviert werden. Ist diese aktiviert, startet BeeSMART automatisch einen neuen Zapfvorgang, wenn ein neues leeres Glas auf der Waage erkannt wird.

\subsection{Einstellungen}

\begin{center}
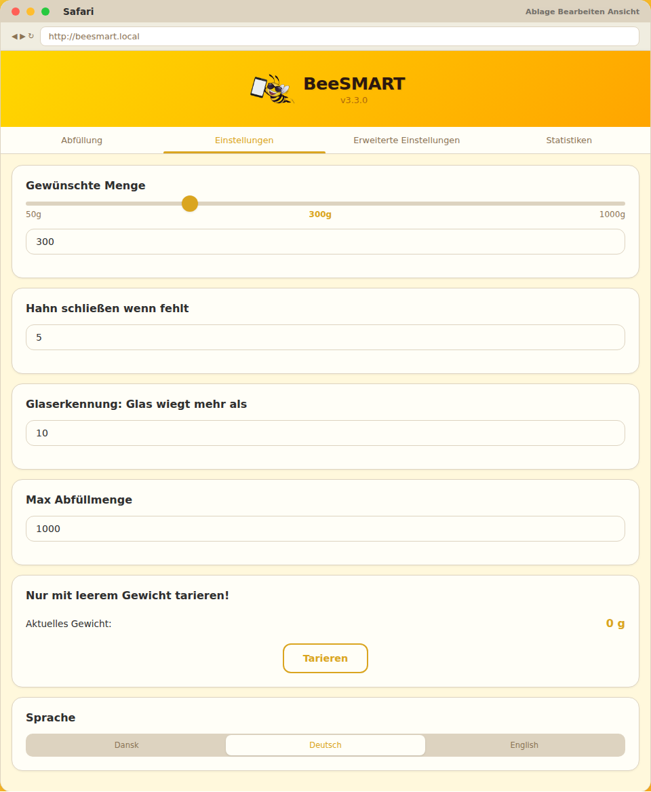
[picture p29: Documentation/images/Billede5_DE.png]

\end{center}

Auf der Seite \textit{Einstellungen} können folgende Optionen konfiguriert werden:

\begin{itemize}[leftmargin=*]
    \item \textbf{Gewünschte Menge} (Honig ohne Glas)
    \item \textbf{Schließe Hahn, wenn noch X g fehlen}
    \item \textbf{Glaserkennung: Glas wiegt mehr als}
    \item \textbf{Maximale Zapfmenge}
    \item \textbf{Tara} (Zurücksetzen der Waage)
    \item \textbf{Sprachauswahl} (z. B. Dänisch, Deutsch, Englisch)
\end{itemize}

\subsubsection*{Schließe Hahn, wenn noch X g fehlen}

Diese Einstellung gibt an, wie viele Gramm vor der gewünschten Menge der Hahn vollständig geschlossen wird. Sie dient dazu, für Tropfen und die letzte verbleibende Honigmenge nach dem Schließen zu kompensieren.

\subsubsection*{Glaserkennung}

Die Grenze für das Glasgewicht gibt an, wie schwer ein leeres Glas mindestens sein muss, um erkannt zu werden. Dies verhindert ein Befüllen ohne Glas auf der Waage.

\subsubsection*{Maximale Zapfmenge}

Dieser Wert erhöht das Maximum des Schiebereglers \textit{Gewünschte Menge}, wenn größere Mengen abgefüllt werden sollen. Standard‑Maximum, das die Waage handhaben kann, ist 5 kg.

\subsubsection*{Tara}

\textbf{Tara} setzt die Waage zurück. Wird bei leerer Waage verwendet.

\newpage

% ---------------------------------------------------------
% 5. Erweitert
% ---------------------------------------------------------
\section{Erweitert}

Auf der Seite \textit{Erweitert} können Regelparameter (PID), der Hub des Servos und die Kalibrierung der Waage angepasst werden.

\begin{center}
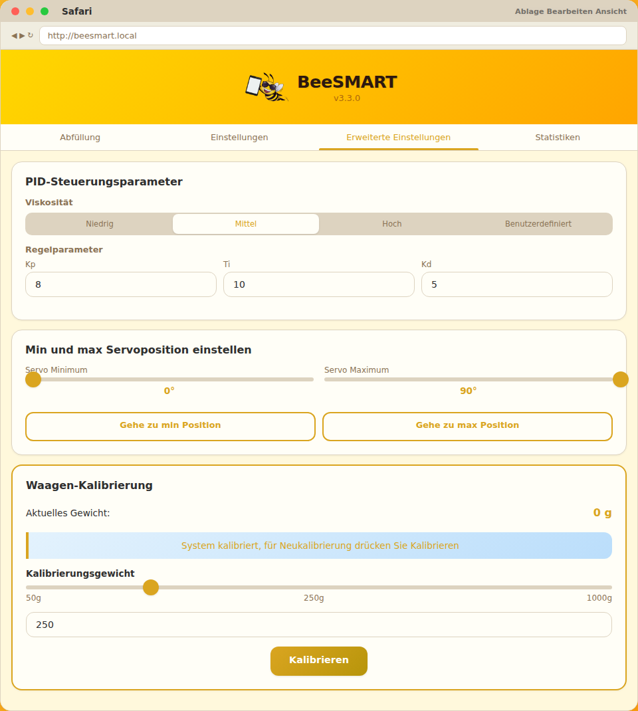
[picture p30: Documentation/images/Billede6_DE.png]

\end{center}

Die Waage ist von Werk aus kalibriert. Eine Neukalibrierung ist normalerweise nur erforderlich, wenn deutliche Abweichungen beobachtet werden.

\subsection{PID Regelparameter}

BeeSMART verwendet PID‑ähnliche Regelparameter, um die Öffnung des Servos in Bezug auf das gemessene Gewicht zu steuern. Es stehen vordefinierte Viskositätsprofile zur Auswahl:

\begin{itemize}[leftmargin=*]
    \item \textbf{Niedrig} – für dünneren Honig/Flüssigkeit
    \item \textbf{Medium} – Standardeinstellung
    \item \textbf{Hoch} – für sehr zähflüssigen Honig
    \item \textbf{Benutzerdefiniert} – freie Einstellung von Kp, Ti und Kd
\end{itemize}

Die Standardwerte, die häufig gut funktionieren, sind:
\begin{itemize}[leftmargin=*]
    \item Kp = 8
    \item Ti = 7
    \item Kd = 2
\end{itemize}

\subsubsection*{Kp (Proportionaler Anteil)}

Kp wird mit der Differenz zwischen gewünschtem Gewicht und aktuellem Gewicht im Glas multipliziert — also mit der fehlenden Menge. Ein kleines Kp führt zu einer kleinen Hahnöffnung, während ein größeres Kp für denselben Fehler eine größere Öffnung bewirkt.

\begin{itemize}[leftmargin=*]
    \item Größeres Kp bedeutet in der Regel schnelleres Befüllen.
    \item Zu großes Kp erhöht das Risiko eines Überschreitens der gewünschten Menge.
\end{itemize}

\subsubsection*{Ti (Integral/Zeitenkonstante)}

Ti beschreibt die \textit{Geduld} des Systems. Ein kleines Ti bedeutet, dass das System schneller auf fehlende Honigmenge reagiert und stärker öffnet. Ein großes Ti führt zu langsameren Reaktionen.

\begin{itemize}[leftmargin=*]
    \item Kleineres Ti führt zu schnellerer Hochregelung.
    \item Zu kleines Ti kann zu Überschwingungen und Instabilität führen.
\end{itemize}

\subsubsection*{Kd (Differentialanteil)}

Kd reagiert auf die Geschwindigkeit der Gewichtszunahme. Füllt das Glas sehr schnell, trägt Kd dazu bei, die Servoöffnung vorübergehend zu reduzieren, damit die Füllgeschwindigkeit sinkt. Wenn die Gewichtszunahme wieder kleiner wird, verliert Kd seine Wirkung und der Hahn kann wieder weiter öffnen.

\begin{itemize}[leftmargin=*]
    \item Zu hohes Kd kann ein \textit{öffnen–schließen–öffnen} Verhalten verursachen.
    \item Kd kann nützlich sein, um Überschreitungen zu vermeiden, wenn das Fass sehr voll ist oder der Honig relativ dünnflüssig ist.
    \item In der Regel kann Kd oft auf 0 gesetzt werden, es sei denn, eine zusätzliche Dämpfung ist erforderlich.
\end{itemize}

\subsubsection*{Allgemeine Empfehlungen}

\begin{itemize}[leftmargin=*]
    \item Größeres Kp = schnelleres Befüllen, aber größeres Risiko für Überschreiten.
    \item Kleineres Ti = schnelleres Befüllen, aber größeres Risiko für Überschwingen.
    \item Kd sollte nur vorsichtig und in kleinen Schritten erhöht werden.
\end{itemize}

\subsection{Servo‑Einstellung}

Auf derselben Seite können \textit{Servo Minimum} und \textit{Servo Maximum} eingestellt werden. Es gibt Tasten, um den Servo auf Minimum bzw. Maximum zu fahren, damit die Einstellung getestet werden kann.

\subsubsection*{Einstellung des Servo‑Hubes}

\begin{enumerate}[leftmargin=*]
    \item Entfernen Sie das Servo‑Horn vom Servo.
    \item Stellen Sie sicher, dass der Zapfhahn physisch geschlossen ist.
    \item Setzen Sie \textit{Servo Minimum} auf einen geeigneten Wert und fahren Sie den Servo zur Minimalposition.
    \item Montieren Sie das Servo‑Horn so, dass der Hahn in der Minimalposition gerade geschlossen ist, und ziehen Sie die Schraube fest.
    \item Erhöhen Sie \textit{Servo Maximum} schrittweise, während Sie die Öffnung testen, bis eine passende Vollöffnung erreicht ist.
\end{enumerate}

\begin{center}
    \begin{minipage}{0.45\textwidth}
        \centering
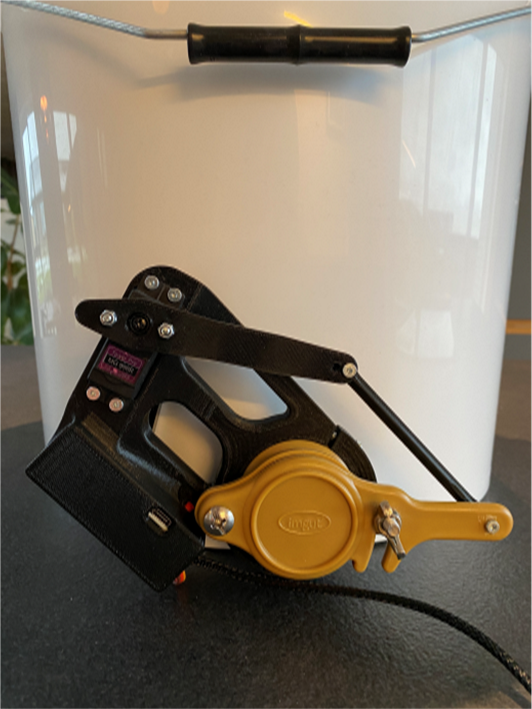
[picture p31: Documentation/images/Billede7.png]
        
    \end{minipage}
    \hfill
    \begin{minipage}{0.45\textwidth}
        \centering
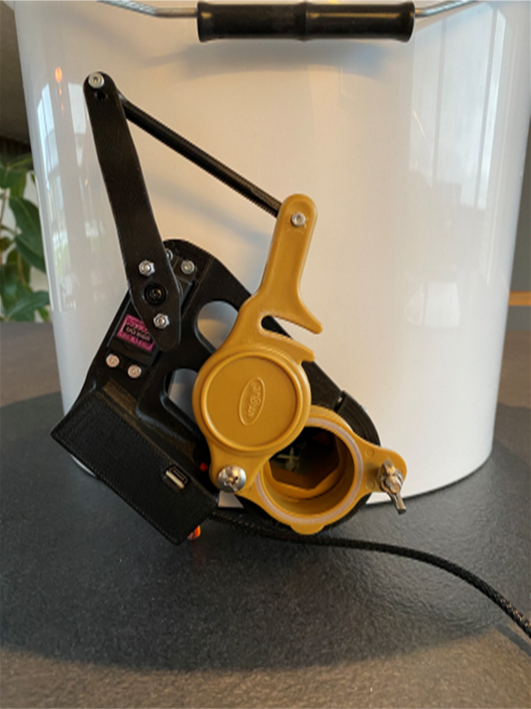
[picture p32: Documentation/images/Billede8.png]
        
    \end{minipage}
\end{center}

\subsection{Waagenkalibrierung}

Die Waage wird kalibriert geliefert. Eine Kalibrierung ist normalerweise nur erforderlich, wenn wiederholt systematische Abweichungen gemessen werden.

Auf der Seite wird ein Kalibrierungsgewicht gewählt (z. B. 50 g, 283 g oder 1000 g), wonach dem Kalibrierungsverfahren gefolgt wird. HINWEIS: Die Waage muss leer sein, wenn \textit{Kalibrieren} gedrückt wird. Es wird empfohlen, ein möglichst genaues Referenzgewicht zu verwenden.

\newpage

% ---------------------------------------------------------
% 6. Regelparameter – Details
% ---------------------------------------------------------
\section{Regelparameter – Details}

Die Regelparameter Kp, Ti und Kd arbeiten zusammen, um die Füllgeschwindigkeit zu steuern und sicherzustellen, dass das gewünschte Gewicht so genau wie möglich erreicht wird.

\subsection*{Beim Anpassen der Parameter}

\begin{itemize}[leftmargin=*]
    \item Beginnen Sie immer mit den Standardwerten.
    \item Passen Sie jeweils nur einen Parameter an.
    \item Verwenden Sie die Statistik‑Seite, um die Ergebnisse über mehrere Zapfvorgänge zu bewerten.
\end{itemize}

\subsection*{Typische Szenarien}

\begin{itemize}[leftmargin=*]
    \item Wenn die Zapfvorgänge typischerweise unter dem gewünschten Gewicht enden, können Kp oder Ti erhöht werden.
    \item Wenn häufig zu viel abgefüllt wird, kann Kp verringert und/oder Ti erhöht werden; ggf. kann Kd leicht erhöht werden.
    \item Bei sehr zähem Honig kann ein größeres Kp erforderlich sein, um einen guten Durchfluss zu erreichen.
\end{itemize}

\newpage

% ---------------------------------------------------------
% 7. Statistiken
% ---------------------------------------------------------
\section{Statistiken}

Die Statistik‑Seite gibt einen Überblick darüber, wie genau die Zapfvorgänge im Verhältnis zum gewünschten Gewicht lagen.

\begin{center}
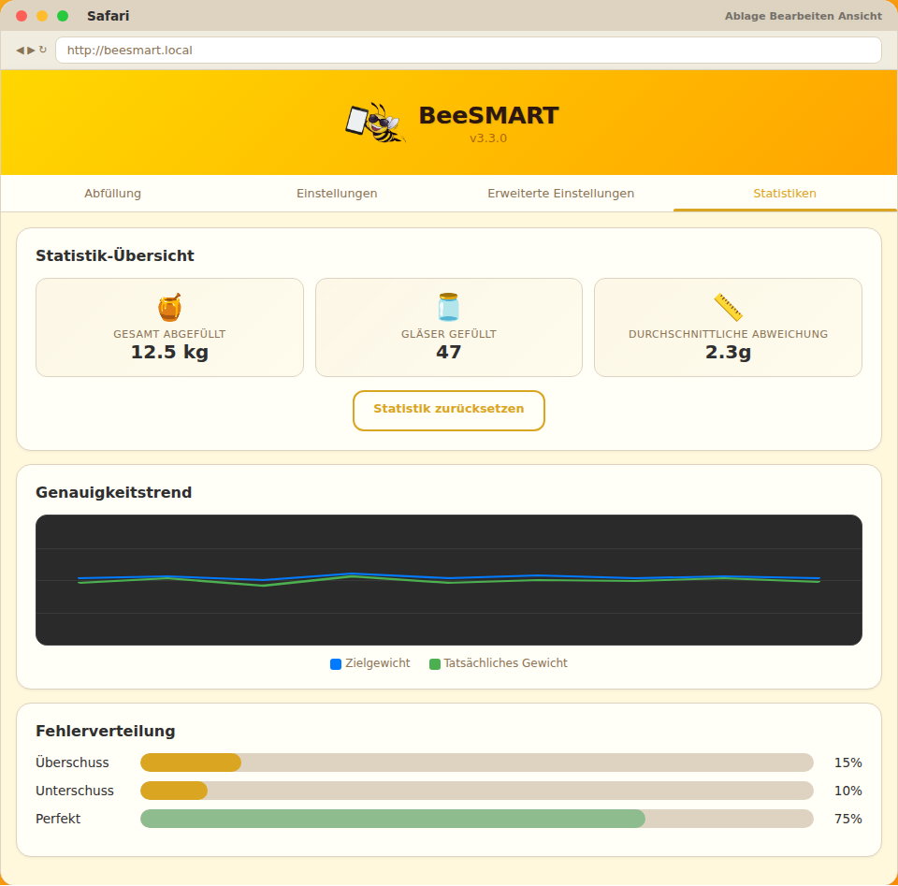
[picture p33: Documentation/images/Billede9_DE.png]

\end{center}

Typischerweise werden angezeigt:

\begin{itemize}[leftmargin=*]
    \item \textbf{Gesamte abgefüllte Menge} (z. B. in kg)
    \item \textbf{Anzahl gefüllter Gläser}
    \item \textbf{Durchschnittliche Abweichung} in Gramm
    \item \textbf{Diagramm der letzten 10 Zapfvorgänge} (gewünscht vs. tatsächlich)
    \item \textbf{Fehlerverteilung} – Anteil von Überschreitungen, Unterschreitungen und \textit{perfekten} Füllungen
\end{itemize}

Diese Daten können verwendet werden, um:

\begin{itemize}[leftmargin=*]
    \item Zu bewerten, ob die Regelparameter passend sind
    \item Zu erkennen, ob systematisch zu viel oder zu wenig abgefüllt wird
    \item Die Produktionsdokumentation und Mengenaufzeichnung zu unterstützen
\end{itemize}

\end{document}

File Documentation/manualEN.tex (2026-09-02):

% ======================================================================
% BeeSMART Manual (Print-Optimized LaTeX Version)
% Style B 
% ======================================================================

\documentclass[11pt,a4paper]{article}

% ---------------------------------------------------------
% Packages
% ---------------------------------------------------------
\usepackage{fontspec}
\usepackage{titlesec}
\usepackage{graphicx}
\usepackage{geometry}
\usepackage{setspace}
\usepackage{hyperref}
\usepackage{xcolor}
\usepackage{tocloft}
\usepackage{parskip}
\usepackage{fancyhdr}
\usepackage{enumitem}
\usepackage[english]{babel}
\usepackage[table]{xcolor}
\usepackage{qrcode}

% ---------------------------------------------------------
% Page Setup
% ---------------------------------------------------------
\geometry{
    a4paper,
    margin=2.2cm
}

\setstretch{1.25}

% ---------------------------------------------------------
% BeeSMART Color Palette (translated from CSS)
% ---------------------------------------------------------
\definecolor{primary}{HTML}{DAA520}        % Golden Rod
\definecolor{primarylight}{HTML}{F4D03F}   % Light golden
\definecolor{primarydark}{HTML}{B7950B}    % Dark golden
\definecolor{secondary}{HTML}{FF8C00}      % Dark orange
\definecolor{accent}{HTML}{FFE135}         % Bright yellow
\definecolor{success}{HTML}{8FBC8F}        % Muted green
\definecolor{destructive}{HTML}{CD853F}    % Peru
\definecolor{warning}{HTML}{F0E68C}        % Khaki
\definecolor{textprimary}{HTML}{2F2F2F}    % Dark gray
\definecolor{textsecondary}{HTML}{8B7355}  % Warm brown-gray
\definecolor{separator}{HTML}{DDD3C0}      % Beige

% ---------------------------------------------------------
% Fonts (Cooper Black + Fredoka One)
% ---------------------------------------------------------
\setmainfont{Segoe UI}[
    Ligatures=TeX
]

\newfontfamily\cooper{Cooper Black}
\newfontfamily\fredoka{Fredoka One}

% ---------------------------------------------------------
% Heading Styles
% ---------------------------------------------------------
\titleformat{\section}
  {\large\bfseries\cooper\color{primarydark}}
  {\thesection}{1em}{}

\titleformat{\subsection}
  {\normalsize\bfseries\fredoka\color{secondary}}
  {\thesubsection}{1em}{}

\titleformat{\subsubsection}
  {\normalsize\bfseries\color{textprimary}}
  {\thesubsubsection}{1em}{}

% ---------------------------------------------------------
% Table of Contents Styling
% ---------------------------------------------------------
\renewcommand{\cftsecleader}{\cftdotfill{\cftdotsep}}

% ---------------------------------------------------------
% Hyperlink Colors
% ---------------------------------------------------------
\hypersetup{
    colorlinks=true,
    linkcolor=primarydark,
    urlcolor=secondary
}

% ---------------------------------------------------------
% Headers and Footers
% ---------------------------------------------------------
\pagestyle{fancy}
\fancyhf{} % clear all
\lhead{\textcolor{textsecondary}{BeeSMART Manual}}
\rhead{\textcolor{textsecondary}{\leftmark}}
\cfoot{\textcolor{textsecondary}{\thepage}}
\renewcommand{\headrulewidth}{0.4pt}
\renewcommand{\headrule}{\hbox to\headwidth{\color{separator}\leaders\hrule height \headrulewidth\hfill}}
\renewcommand{\footrulewidth}{0pt}

% ---------------------------------------------------------
% Document Start
% ---------------------------------------------------------
\begin{document}

% ---------------------------------------------------------
% Cover Page
% ---------------------------------------------------------
\begin{titlepage}
    \centering
    {\cooper\fontsize{28}{32}\selectfont BeeSMART Manual}\\[1.5em]
    {\fredoka\Large Wi-Fi controlled tap/fill machine}\\[1em]
    {\large Version 3.0}\\[3em]

    \\[3em]

    {\small Developed by Mogens Groth Nicolaisen}\\
    {\small Last updated: June 2026}

\end{titlepage}

\newpage

% ---------------------------------------------------------
% Table of Contents
% ---------------------------------------------------------
\tableofcontents
\newpage

% ---------------------------------------------------------
% 1. Introduction
% ---------------------------------------------------------
\section{Introduction}

BeeSMART is a Wi\u2009Fi based honey dispensing system focused on few components, simple operation and relatively low cost. The system can of course also be used for other liquids where weight-based filling is desired.

The system is browser-based and requires no app. Access it from a PC, tablet or smartphone as long as the device can connect to the BeeSMART Wi\u2009Fi.

\begin{center}

\end{center}

The system typically consists of:
\begin{itemize}[leftmargin=*]
    \item BeeSMART module with integrated Wi\u2009Fi control and servo
    \item Servo horn and pushrod
    \item BeeSMART scale (5 kg)
    \item USB-C power supply
    \item Mounting bracket and inserts for different taps
\end{itemize}

The mounting bracket fits taps with a collar of about 54 mm diameter and at least 10 mm width. Inserts for 40 mm collars are included.

\newpage

% ---------------------------------------------------------
% 2. Parts List
% ---------------------------------------------------------
\section{Parts List}

\begin{center}

\end{center}

Contents of a standard BeeSMART kit:

\begin{center}
    \renewcommand{\arraystretch}{1.3}
    
    \begin{tabular}{ll}
        \rowcolor{primarylight!40}
        {\fredoka\textbf{Quantity}} & {\fredoka\textbf{Component}} \\
        
        \rowcolor{primarylight!15}
        2 × & M3 self-locking nut \\
        
        \rowcolor{primarylight!5}
        2 × & M4 nut \\
        
        \rowcolor{primarylight!15}
        1 × & M3 × 16 screw \\
        
        \rowcolor{primarylight!5}
        1 × & M3 × 25 screw \\
        
        \rowcolor{primarylight!15}
        2 × & M4 × 25 screw \\
        
        \rowcolor{primarylight!5}
        1 × & BeeSMART module with servo and Wi\u2009Fi control \\
        
        \rowcolor{primarylight!15}
        1 × & Pushrod \\
        
        \rowcolor{primarylight!5}
        1 × & Servo horn, extension and screw \\
        
        \rowcolor{primarylight!15}
        2 × & Inserts for 40 mm tap \\
        
        \rowcolor{primarylight!5}
        1 × & 5 kg BeeSMART scale \\
        
        \rowcolor{primarylight!15}
        1 × & USB-C power supply \\
        
    \end{tabular}
\end{center}
\newpage

% ---------------------------------------------------------
% 3. Video material
% ---------------------------------------------------------
\section{Video material}

There are videos for BeeSMART covering:

\begin{itemize}[leftmargin=*]
    \item Assembly and mounting of BeeSMART
    \item Demonstration of dispensing functions
    \item Usage examples with different settings
\end{itemize}

\vspace{2em}
The videos are especially useful during initial setup and for fine-tuning the servo and control parameters.
\vspace{2em}

\begin{center}
	\begin{tabular}{cc}
		
		% ------------------ Row 1, Col 1 ------------------
		\begin{minipage}{0.45\textwidth}
			\centering
			\qrcode[height=3.5cm]{https://youtu.be/7Y-k81tILdg}\\[0.3em]
			
			\href{https://youtu.be/7Y-k81tILdg}{%
				{\fredoka\color{primarydark}\Large Demo 1}%
			}\\[-0.2em]
			
			\href{https://youtu.be/7Y-k81tILdg}{%
				{\small BeeSMART in use}%
			}
		\end{minipage}
		&
		% ------------------ Row 1, Col 2 ------------------
		\begin{minipage}{0.45\textwidth}
			\centering
			\qrcode[height=3.5cm]{https://youtube.com/shorts/xE0CEP3kYTg}\\[0.3em]
			
			\href{https://youtube.com/shorts/xE0CEP3kYTg}{%
				{\fredoka\color{primarydark}\Large Demo 2}%
			}\\[-0.2em]
			
			\href{https://youtube.com/shorts/xE0CEP3kYTg}{%
				{\small BeeSMART in use}%
			}
		\end{minipage}
		
		\\[8em]
		
		% ------------------ Row 2, Col 1 ------------------
		\begin{minipage}{0.45\textwidth}
			\centering
			\qrcode[height=3.5cm]{https://youtu.be/kUqcvOjCH5E}\\[0.3em]
			
			\href{https://youtu.be/kUqcvOjCH5E}{%
				{\fredoka\color{primarydark}\Large Demo 3}%
			}\\[-0.2em]
			
			\href{https://youtu.be/kUqcvOjCH5E}{%
				{\small Advanced features in 3.0}%
			}
		\end{minipage}
		&
		% ------------------ Row 2, Col 2 ------------------
		\begin{minipage}{0.45\textwidth}
			\centering
			\qrcode[height=3.5cm]{https://youtu.be/ojsv-gZ6waY}\\[0.3em]
			
			\href{https://youtu.be/ojsv-gZ6waY}{%
				{\fredoka\color{primarydark}\Large Mounting}%
			}\\[-0.2em]
			
			\href{https://youtu.be/ojsv-gZ6waY}{%
				{\small Tap and bracket}%
			}
		\end{minipage}
		
	\end{tabular}
\end{center}

\newpage

% ---------------------------------------------------------
% 4. User guide
% ---------------------------------------------------------
\section{User guide}

\subsection{Connection and access}

After connecting USB power, the servo and the scale, BeeSMART will create a Wi\u2009Fi Access Point. This should appear within approximately 30 seconds. If not, briefly press the reset button on the module.

\begin{center}

\end{center}

Connect to the displayed BeeSMART network from a PC, tablet or smartphone. In many cases a browser will open automatically with the BeeSMART interface. If this does not happen, open a browser manually and enter the following address:

\begin{verbatim}
beesmart.local
\end{verbatim}

\noindent Alternatively, the IP address \texttt{192.168.4.1} can also be used.

\subsection{Main screen}

\begin{center}
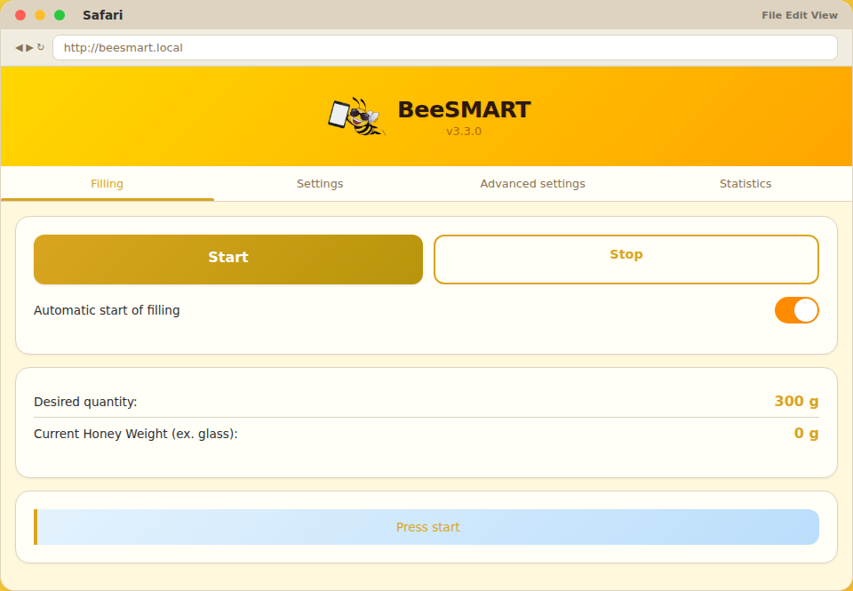
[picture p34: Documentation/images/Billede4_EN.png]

\end{center}

The main screen provides an overview of:

\begin{itemize}[leftmargin=*]
    \item Desired quantity to be dispensed (excluding jar)
    \item Current weight on the scale
    \item Status text at the bottom describing what the system is doing
\end{itemize}

The \textbf{Start} button begins a dispense cycle, while \textbf{Stop} interrupts a running dispense.

The \textbf{Automatic start of dispensing} feature can be enabled via a switch. When enabled, BeeSMART will automatically start a new dispense when a new empty jar is detected on the scale.

\subsection{Settings}

\begin{center}
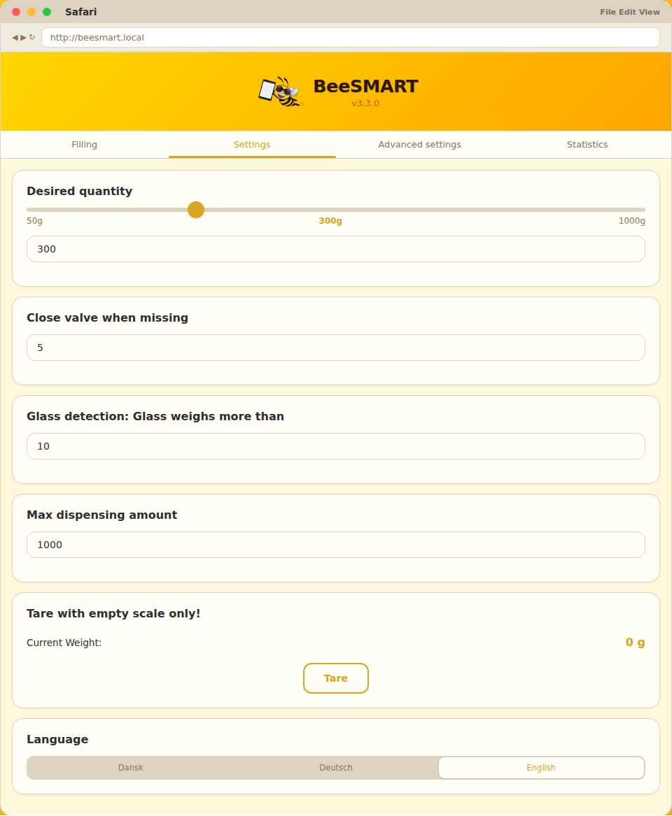
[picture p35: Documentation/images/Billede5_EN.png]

\end{center}

On the \textit{Settings} page you can configure:

\begin{itemize}[leftmargin=*]
    \item \textbf{Desired quantity} (honey without jar)
    \item \textbf{Close tap when X g remain}
    \item \textbf{Jar detection: Jar weighs more than}
    \item \textbf{Max dispense quantity}
    \item \textbf{Tare} (reset scale)
    \item \textbf{Language selection} (e.g. Danish, German, English)
\end{itemize}

\subsubsection*{Close tap when X g remain}

This setting specifies how many grams before the desired quantity the tap is fully closed. It compensates for dripping and the last honey remaining after closing.

\subsubsection*{Jar detection}

The jar weight threshold sets how heavy an empty jar must be to be detected. This prevents dispensing without a jar on the scale.

\subsubsection*{Max dispense quantity}

This value increases the maximum of the \textit{Desired quantity} slider if larger fills are needed. The default maximum the scale can handle is 5 kg.

\subsubsection*{Tare}

\textbf{Tare} resets the scale. Use with an empty scale.

\newpage

% ---------------------------------------------------------
% 5. Advanced
% ---------------------------------------------------------
\section{Advanced}

On the \textit{Advanced} page you can adjust control parameters (PID), the servo travel and the scale calibration.

\begin{center}
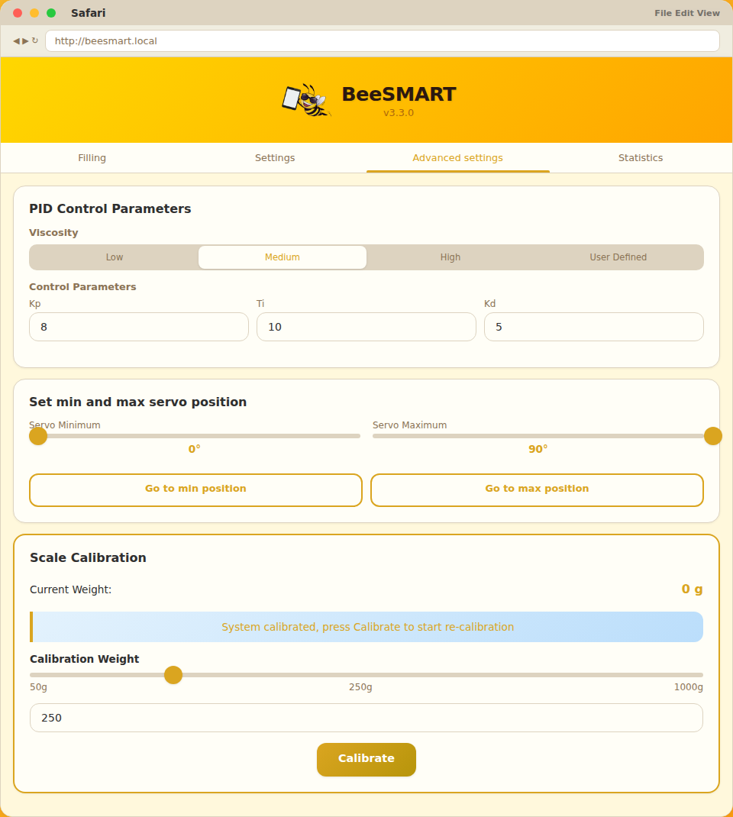
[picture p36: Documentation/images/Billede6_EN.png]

\end{center}

The scale is calibrated at the factory. Calibration is normally not required unless significant deviations are observed.

\subsection{PID control parameters}

BeeSMART uses PID-like control parameters to control servo opening relative to measured weight. Predefined viscosity profiles are available:

\begin{itemize}[leftmargin=*]
    \item \textbf{Low} – for thinner honey/liquid
    \item \textbf{Medium} – default
    \item \textbf{High} – for very thick honey
    \item \textbf{Custom} – free adjustment of Kp, Ti and Kd
\end{itemize}

Typical default values that often work well are:
\begin{itemize}[leftmargin=*]
    \item Kp = 8
    \item Ti = 7
    \item Kd = 2
\end{itemize}

\subsubsection*{Kp (Proportional)}

Kp is multiplied by the difference between desired weight and current weight in the jar — i.e. the missing amount. A small Kp yields a small tap opening, while a larger Kp yields a larger opening for the same error.

\begin{itemize}[leftmargin=*]
    \item Larger Kp typically means faster filling.
    \item Too large Kp increases the risk of overfilling.
\end{itemize}

\subsubsection*{Ti (Integral/time constant)}

Ti describes the system's \textit{patience}. A small Ti means the system reacts quickly to missing honey and opens more. A large Ti causes slower reactions.

\begin{itemize}[leftmargin=*]
    \item Smaller Ti leads to faster correction.
    \item Too small Ti can cause overshoot and instability.
\end{itemize}

\subsubsection*{Kd (Derivative)}

Kd reacts to how fast the weight is changing. If the jar fills very fast, Kd helps temporarily reduce servo opening so the rate slows. When the weight change becomes smaller again, Kd loses effect and the tap can open more.

\begin{itemize}[leftmargin=*]
    \item Too high Kd can cause an \textit{open–close–open} behavior.
    \item Kd can help avoid overshoot when the source is nearly empty or the honey is relatively thin.
    \item Generally Kd can often be set to 0 unless extra damping is needed.
\end{itemize}

\subsubsection*{General recommendations}

\begin{itemize}[leftmargin=*]
    \item Larger Kp = faster filling, but higher risk of overshoot.
    \item Smaller Ti = faster filling, but higher risk of overshoot.
    \item Increase Kd only cautiously and in small steps.
\end{itemize}

\subsection{Servo setup}

On the same page you can set \textit{Servo Minimum} and \textit{Servo Maximum}. Buttons are provided to move the servo to min and max positions for testing.

\subsubsection*{Setting servo travel}

\begin{enumerate}[leftmargin=*]
    \item Remove the servo horn from the servo.
    \item Ensure the tap is physically closed.
    \item Set \textit{Servo Minimum} to a suitable value and move the servo to the min position.
    \item Mount the servo horn so the tap is just closed in the min position and tighten the screw.
    \item Increase \textit{Servo Maximum} gradually while testing the opening until a suitable full opening is reached.
\end{enumerate}

\begin{center}
    \begin{minipage}{0.45\textwidth}
        \centering
        
    \end{minipage}
    \hfill
    \begin{minipage}{0.45\textwidth}
        \centering
        
    \end{minipage}
\end{center}

\subsection{Scale calibration}

The scale is delivered calibrated. Calibration is normally only necessary if systematic deviations are repeatedly observed.

On the page select a calibration weight (e.g. 50 g, 283 g or 1000 g) and follow the calibration procedure. NOTE: The scale must be empty when pressing "Calibrate". Use a as-accurate reference weight as possible.

\newpage

% ---------------------------------------------------------
% 6. Control parameters — Details
% ---------------------------------------------------------
\section{Control parameters — Details}

The control parameters Kp, Ti and Kd work together to control fill speed and ensure the desired weight is reached as accurately as possible.

\subsection*{When adjusting parameters}

\begin{itemize}[leftmargin=*]
    \item Always start from the default values.
    \item Adjust only one parameter at a time.
    \item Use the Statistics page to evaluate results over multiple fills.
\end{itemize}

\subsection*{Typical scenarios}

\begin{itemize}[leftmargin=*]
    \item If fills typically end below the desired weight, increase Kp or Ti.
    \item If often overfilled, decrease Kp and/or increase Ti; consider slightly increasing Kd.
    \item Very thick honey may require larger Kp to maintain good flow.
\end{itemize}

\newpage

% ---------------------------------------------------------
% 7. Statistics
% ---------------------------------------------------------
\section{Statistics}

The Statistics page provides an overview of how fills performed relative to the desired weight.

\begin{center}
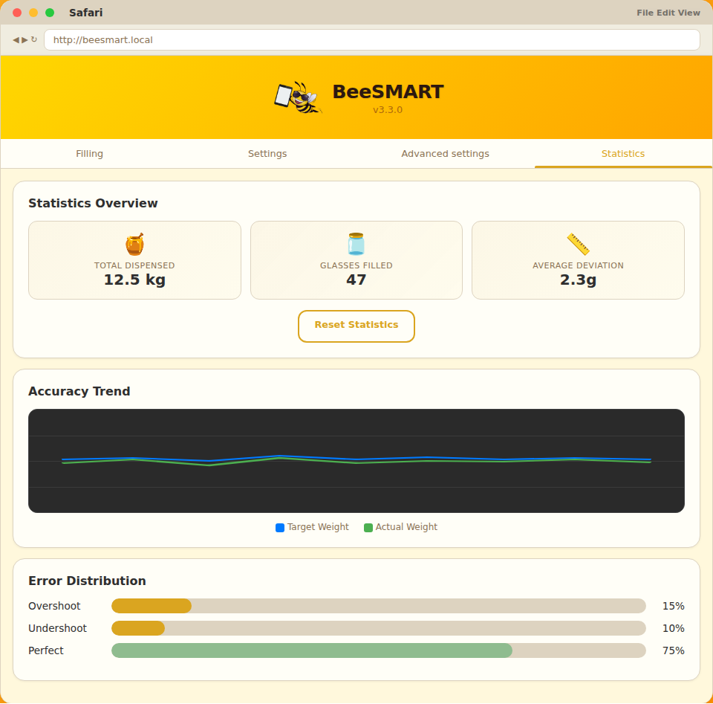
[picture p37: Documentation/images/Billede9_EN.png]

\end{center}

Typically shown:

\begin{itemize}[leftmargin=*]
    \item \textbf{Total dispensed volume} (e.g. in kg)
    \item \textbf{Number of jars filled}
    \item \textbf{Average deviation} in grams
    \item \textbf{Graph of last 10 fills} (desired vs actual)
    \item \textbf{Error distribution} — share of overfills, underfills and \textit{perfect} fills
\end{itemize}

These data can be used to:

\begin{itemize}[leftmargin=*]
    \item Evaluate if control parameters are suitable
    \item Identify systematic overfilling or underfilling
    \item Support production documentation and quantity tracking
\end{itemize}

\end{document}

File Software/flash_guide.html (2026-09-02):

# BeeSMART

Software Flasher & Calibration Guide

English Deutsch Dansk

## Overview — Two Main Steps

1. Flash software — Load new firmware onto your BeeSMART controller via USB.
2. Calibrate scale — Connect everything and calibrate the scale so it weighs accurately.

Total time: ~5–10 minutes. No special tools needed.

1 Open the BeeSMART Software Flasher

Double-click BeeSMART_Flasher.exe (Windows) or run beesmart_flasher.py (Linux/Mac). The window below will appear.

BeeSMART Software Flasher · v3.3.0

Firmware Binary

No file selected

Browse

Select a firmware binary to begin

BeeSMART Honey Dosing System v3.3.0

Tip: On Windows you may see a SmartScreen warning the first time — click More info → Run anyway.

2 Select the Firmware File

Click Browse and navigate to the firmware file you downloaded. It should be a .bin file (e.g. honeyDosing_v3_firmware.bin).

BeeSMART Software Flasher · v3.3.0

Firmware Binary

honeyDosing_v3_firmware.bin

Browse

Ready to flash — connect your BeeSMART controller via USB

BeeSMART Honey Dosing System v3.3.0

Tip: The status bar now shows "Ready to flash — connect your BeeSMART controller via USB". The tool is waiting for your device.

3 Connect the BeeSMART Controller via USB

Plug the BeeSMART controller into your computer with a USB cable. The flasher will automatically detect the device and start flashing.

BeeSMART Software Flasher · v3.3.0

Firmware Binary

honeyDosing_v3_firmware.bin

Browse

Flashing on COM5...

BeeSMART Honey Dosing System v3.3.0

Important: Do not unplug the USB cable while flashing is in progress. This could damage the controller.

4 Wait for Flashing to Complete

The progress bar will fill up and the status will turn green saying "Device flashed successfully".

BeeSMART Software Flasher · v3.3.0

Firmware Binary

honeyDosing_v3_firmware.bin

Browse

Device flashed successfully

BeeSMART Honey Dosing System v3.3.0

Tip: If you see "Flashing failed", try unplugging and re-plugging the USB, then repeat steps 3–4.

5 Close the Flasher

Once the status shows "Device flashed successfully", you can close the flasher window. Your BeeSMART controller now has the new software installed.

BeeSMART Software Flasher · v3.3.0

Firmware Binary

honeyDosing_v3_firmware.bin

Browse

Device flashed successfully

BeeSMART Honey Dosing System v3.3.0

6 Connect the Scale to the Controller

Use the RJ45 cable to connect the BeeSMART scale to the BeeSMART controller. Plug one end into the scale and the other into the controller's RJ45 port.

🔌 ─── RJ45 ─── 🔌

Scale ←——————→ Controller

7 Connect to the BeeSMART Wi-Fi

On your phone, tablet, or computer, open the Wi-Fi settings and look for a network named BeeSMART-XXXXXXXX (the X's are unique to your device). Connect to it. No password is required.

📶

BeeSMART-A3F2C1B0

Wi-Fi network · No password

Tip: Once connected, your device should automatically show the BeeSMART web interface (captive portal). If it doesn't, open a browser and go to http://beesmart.local or http://192.168.4.1.

8 Open the Web Interface

Once connected to the BeeSMART Wi-Fi, the captive portal should open automatically. If not, type http://beesmart.local in your browser's address bar. You will see the BeeSMART web interface with the Filling tab active.

●●● Safari File Edit View

◀ ▶ ↻

http://beesmart.local

BeeSMART

v3.3.0

Filling

Settings

Advanced

Statistics

Start

Stop

Automatic tap start

Desired Amount: 300 g

Current Honey Weight (without jar): 0 g

Press Start

9 Go to the Advanced Tab

In the web interface, tap on "Advanced" (the third tab) to open the advanced settings. Scroll down to the Scale Calibration section.

●●● Safari

◀ ▶ ↻

http://beesmart.local

BeeSMART

v3.3.0

Filling

Settings

Advanced

Statistics

PID Control Parameters

Viscosity

Low Medium High User Defined

Control Parameters

Kp

8

Ti

10

Kd

5

Set Min and Max Servo Position

Servo Minimum

0°

Servo Maximum

90°

Go to min position Go to max position

Scale Calibration

Current Weight: 0 g

System calibrated, press Calibrate to start re-calibration

Calibration Weight

50g250g1000g

250

Calibrate

10 Start Calibration — Remove Weight & Press Calibrate

Make sure nothing is on the scale. In the Scale Calibration section (bottom of the Advanced tab), press the "Calibrate" button. The system will tare the scale.

●●● Safari

◀ ▶ ↻

http://beesmart.local

BeeSMART

Filling

Settings

Advanced

Statistics

Scale Calibration

Current Weight: 0 g

Remove any weight from scale and press Calibrate

Calibration Weight

50g250g1000g

250

Calibrate

11 Place a Known Weight & Calibrate Again

Find an item with a known weight (e.g. a 250g calibration weight, a bag of sugar, or a can of beans — check the label). Place it on the scale. Enter the exact weight in the Calibration Weight field. Press "Calibrate" again.

●●● Safari

◀ ▶ ↻

http://beesmart.local

BeeSMART

Filling

Settings

Advanced

Statistics

Scale Calibration

Current Weight: 250 g

Place calibration weight on scale and press calibrate

Calibration Weight

50g250g1000g

250

Calibrate

Tip: Any item with the weight printed on the package works — a bag of flour, a bottle of water, etc. The more accurate your reference weight, the better your scale will perform.

12 Wait for Calibration Complete

During sampling the progress bar fills to 100% while the status shows "Calibrating...". When it finishes, the status returns to "System calibrated, press Calibrate to start re-calibration" — your scale is now calibrated and ready for use!

●●● Safari

◀ ▶ ↻

http://beesmart.local

BeeSMART

Filling

Settings

Advanced

Statistics

Scale Calibration

Current Weight: 0 g

System calibrated, press Calibrate to start re-calibration

Calibration Weight

50g250g1000g

250

Calibrate

BeeSMART

Your BeeSMART is ready!

Enjoy precise, automatic honey dosing.

## Übersicht — Zwei Hauptschritte

1. Software flashen — Neue Firmware über USB auf den BeeSMART-Controller laden.
2. Waage kalibrieren — Alles verbinden und die Waage kalibrieren, damit sie genau wiegt.

Gesamtzeit: ~5–10 Minuten. Kein Spezialwerkzeug nötig.

1 Öffnen Sie den BeeSMART Flasher

Doppelklicken Sie BeeSMART_Flasher.exe (Windows) oder führen Sie beesmart_flasher.py (Linux/Mac) aus.

BeeSMART Software Flasher · v3.3.0

Firmware Binary

Keine Datei ausgewählt

Durchsuchen

Wählen Sie eine Firmware-Datei

BeeSMART Honey Dosing System v3.3.0

Hinweis: Unter Windows erscheint möglicherweise eine SmartScreen-Warnung — klicken Sie Weitere Informationen → Trotzdem ausführen.

2 Firmware-Datei auswählen

Klicken Sie Durchsuchen und wählen Sie die .bin-Datei aus (z. B. honeyDosing_v3_firmware.bin).

BeeSMART Software Flasher · v3.3.0

Firmware Binary

honeyDosing_v3_firmware.bin

Durchsuchen

Bereit — BeeSMART-Controller via USB verbinden

BeeSMART Honey Dosing System v3.3.0

3 Controller per USB anschließen

Verbinden Sie den BeeSMART-Controller per USB mit dem Computer. Der Flasher erkennt das Gerät automatisch und beginnt mit dem Flashen.

BeeSMART Software Flasher · v3.3.0

Firmware Binary

honeyDosing_v3_firmware.bin

Durchsuchen

Flashen auf COM5...

BeeSMART Honey Dosing System v3.3.0

Wichtig: Ziehen Sie das USB-Kabel während des Flashvorgangs nicht ab. Dies könnte den Controller beschädigen.

4 Warten bis der Vorgang abgeschlossen ist

Der Fortschrittsbalken füllt sich und die Statusmeldung wird grün: "Gerät erfolgreich geflasht".

BeeSMART Software Flasher · v3.3.0

Firmware Binary

honeyDosing_v3_firmware.bin

Durchsuchen

Gerät erfolgreich geflasht

BeeSMART Honey Dosing System v3.3.0

Hinweis: Bei "Flashing failed" trennen Sie das USB-Kabel kurz und schließen es erneut an. Wiederholen Sie dann Schritt 3–4.

5 Flasher schließen

Sobald "Gerät erfolgreich geflasht" angezeigt wird, können Sie das Fenster schließen. Der Controller hat jetzt die neue Software.

BeeSMART Software Flasher · v3.3.0

Firmware Binary

honeyDosing_v3_firmware.bin

Durchsuchen

Gerät erfolgreich geflasht

BeeSMART Honey Dosing System v3.3.0

6 Waage mit dem Controller verbinden

Verbinden Sie die BeeSMART-Waage mit dem RJ45-Kabel mit dem Controller.

🔌 ─── RJ45 ─── 🔌

Waage ←——————→ Controller

7 Mit dem BeeSMART-WLAN verbinden

Öffnen Sie die WLAN-Einstellungen Ihres Geräts und wählen Sie BeeSMART-XXXXXXXX. Kein Passwort erforderlich.

📶

BeeSMART-A3F2C1B0

WLAN · Kein Passwort

Hinweis: Nach Verbindung öffnet sich die Weboberfläche automatisch. Falls nicht: http://beesmart.local oder http://192.168.4.1.

8 Weboberfläche öffnen

Nach der Verbindung mit dem BeeSMART-WLAN öffnen Sie einen Browser und gehen zu http://beesmart.local. Sie sehen das BeeSMART-Webinterface mit dem Tab Abfüllung.

●●● Safari

◀ ▶ ↻

http://beesmart.local

BeeSMART

v3.3.0

Abfüllung

Einstellungen

Erweiterte

Statistiken

Start

Stopp

Automatischer Start

Gewünschte Menge: 300 g

Aktuelles Honiggewicht (ohne Glas): 0 g

Start drücken

9 Zum Reiter „Erweiterte Einstellungen"

Tippen Sie auf "Erweiterte Einstellungen", scrollen Sie nach unten zur Waagen-Kalibrierung.

●●● Safari

◀ ▶ ↻

http://beesmart.local

BeeSMART

v3.3.0

Abfüllung

Einstellungen

Erweiterte

Statistiken

PID-Steuerungsparameter

Viskosität

Niedrig Mittel Hoch Benutzerdefiniert

Regelparameter

Kp

8

Ti

10

Kd

5

Min und max Servoposition einstellen

Minimum

0°

Maximum

90°

Waagen-Kalibrierung

Aktuelles Gewicht: 0 g

System kalibriert, für Neukalibrierung drücken Sie Kalibrieren

Kalibrierungsgewicht

50g250g1000g

250

Kalibrieren

10 Kalibrierung starten — Gewicht entfernen

Stellen Sie sicher, dass sich nichts auf der Waage befindet. Drücken Sie "Kalibrieren".

●●● Safari

◀ ▶ ↻

http://beesmart.local

BeeSMART

Abfüllung

Einstellungen

Erweiterte

Statistiken

Waagen-Kalibrierung

Aktuelles Gewicht: 0 g

Gewicht entfernen und Kalibrieren drücken

Kalibrierungsgewicht

50g250g1000g

250

Kalibrieren

11 Bekanntes Gewicht auflegen & erneut kalibrieren

Legen Sie einen Gegenstand mit bekanntem Gewicht auf (z. B. 250g). Geben Sie das Gewicht ein und drücken Sie erneut "Kalibrieren".

●●● Safari

◀ ▶ ↻

http://beesmart.local

BeeSMART

Abfüllung

Einstellungen

Erweiterte

Statistiken

Waagen-Kalibrierung

Aktuelles Gewicht: 250 g

Kalibriergewicht auflegen und Kalibrieren drücken

Kalibrierungsgewicht

50g250g1000g

250

Kalibrieren

Hinweis: Jeder Gegenstand mit aufgedrucktem Gewicht funktioniert — Mehl, Wasserflasche usw.

12 Kalibrierung abschließen

Während der Messung füllt sich der Fortschrittsbalken auf 100%, während "Kalibriert..." angezeigt wird. Danach kehrt der Status zu "System kalibriert, für Neukalibrierung drücken Sie Kalibrieren" zurück — Ihre Waage ist nun kalibriert!

●●● Safari

◀ ▶ ↻

http://beesmart.local

BeeSMART

Abfüllung

Einstellungen

Erweiterte

Statistiken

Waagen-Kalibrierung

Aktuelles Gewicht: 0 g

System kalibriert, für Neukalibrierung drücken Sie Kalibrieren

Kalibrierungsgewicht

50g250g1000g

250

Kalibrieren

BeeSMART

Ihr BeeSMART ist bereit!

Genießen Sie präzises, automatisches Honigdosieren.

## Overblik — To hovedtrin

1. Flash software — Indlæs ny firmware på din BeeSMART-controller via USB.
2. Kalibrér vægten — Forbind alt, og kalibrér vægten.

Tid: ~5–10 minutter. Intet specialværktøj nødvendigt.

1 Åbn BeeSMART Software Flasher

Dobbeltklik på BeeSMART_Flasher.exe (Windows) eller kør beesmart_flasher.py (Linux/Mac).

BeeSMART Software Flasher · v3.3.0

Firmware Binary

Ingen fil valgt

Gennemse

Vælg en firmware-fil for at begynde

BeeSMART Honey Dosing System v3.3.0

Tip: På Windows kan du se en SmartScreen-advarsel første gang — klik More info → Run anyway.

2 Vælg firmware-filen

Klik Gennemse og find den .bin-fil, du har downloadet (f.eks. honeyDosing_v3_firmware.bin).

BeeSMART Software Flasher · v3.3.0

Firmware Binary

honeyDosing_v3_firmware.bin

Gennemse

Klar til at flashe — tilslut din BeeSMART-controller via USB

BeeSMART Honey Dosing System v3.3.0

3 Tilslut BeeSMART-controlleren via USB

Sæt BeeSMART-controlleren i computeren med et USB-kabel. Flasheren registrerer automatisk enheden.

BeeSMART Software Flasher · v3.3.0

Firmware Binary

honeyDosing_v3_firmware.bin

Gennemse

Flasher på COM5...

BeeSMART Honey Dosing System v3.3.0

Vigtigt: Træk ikke USB-kablet ud, mens flashing er i gang.

4 Vent på at flashning er færdig

Statuslinjen viser til sidst grøn tekst med "Enhed blev flashet".

BeeSMART Software Flasher · v3.3.0

Firmware Binary

honeyDosing_v3_firmware.bin

Gennemse

Enhed blev flashet

BeeSMART Honey Dosing System v3.3.0

Tip: Hvis du ser "Flashing failed", så prøv at genindkoble USB-kablet, og gentag trin 3–4.

5 Luk flasheren

Når status viser "Enhed blev flashet", kan du lukke vinduet. Din controller har nu den nye software.

BeeSMART Software Flasher · v3.3.0

Firmware Binary

honeyDosing_v3_firmware.bin

Gennemse

Enhed blev flashet

BeeSMART Honey Dosing System v3.3.0

6 Forbind vægten til controlleren

Brug RJ45-kablet til at forbinde BeeSMART-vægten til controlleren.

🔌 ─── RJ45 ─── 🔌

Vægt ←——————→ Controller

7 Forbind til BeeSMART Wi-Fi

Åbn Wi-Fi-indstillingerne og find netværket BeeSMART-XXXXXXXX. Ingen adgangskode.

📶

BeeSMART-A3F2C1B0

Wi-Fi-netværk · Ingen adgangskode

Tip: Når du er forbundet, åbnes BeeSMART-webgrænsefladen automatisk. Hvis ikke: http://beesmart.local.

8 Åbn webgrænsefladen

Åbn en browser og gå til http://beesmart.local. Du ser BeeSMART-webgrænsefladen med fanen Tapning aktiv.

●●● Safari

◀ ▶ ↻

http://beesmart.local

BeeSMART

v3.3.0

Tapning

Indstillinger

Avanceret

Statistik

Start

Stop

Automatisk start af tapning

Ønsket Mængde: 300 g

Aktuel Honning Vægt (uden glas): 0 g

Tryk start

9 Gå til fanen Avanceret

Tryk på "Avanceret". Rul ned til Vægt Kalibrering.

●●● Safari

◀ ▶ ↻

http://beesmart.local

BeeSMART

v3.3.0

Tapning

Indstillinger

Avanceret

Statistik

PID Kontrol Parametre

Viskositet

Lav Medium Høj Brugerdefineret

Kontrol Parametre

Kp

8

Ti

10

Kd

5

Indstil min og max Servo position

Min

0°

Max

90°

Vægt Kalibrering

Aktuel Vægt: 0 g

System kalibreret, tryk Kalibrer for at starte re-kalibrering

Kalibreringsvægt

50g250g1000g

250

Kalibrer

10 Start kalibrering — fjern vægt

Sørg for, at der intet er på vægten. Tryk på "Kalibrer".

●●● Safari

◀ ▶ ↻

http://beesmart.local

BeeSMART

Tapning

Indstillinger

Avanceret

Statistik

Vægt Kalibrering

Aktuel Vægt: 0 g

Tøm vægt og tryk Kalibrer

Kalibreringsvægt

50g250g1000g

250

Kalibrer

11 Placer kendt vægt & kalibrér igen

Find en genstand med kendt vægt (f.eks. 250g). Placer den på vægten. Indtast vægten og tryk "Kalibrer" igen.

●●● Safari

◀ ▶ ↻

http://beesmart.local

BeeSMART

Tapning

Indstillinger

Avanceret

Statistik

Vægt Kalibrering

Aktuel Vægt: 250 g

Placer kalibreringsvægt og tryk Kalibrer

Kalibreringsvægt

50g250g1000g

250

Kalibrer

Tip: Enhver genstand med vægten trykt på emballagen duer.

12 Vent på kalibrering færdig

Under prøvetagningen fyldes statuslinjen til 100%, mens "Kalibrerer..." vises. Derefter vender status tilbage til "System kalibreret, tryk Kalibrer for at starte re-kalibrering" — din vægt er nu kalibreret!

●●● Safari

◀ ▶ ↻

http://beesmart.local

BeeSMART

Tapning

Indstillinger

Avanceret

Statistik

Vægt Kalibrering

Aktuel Vægt: 0 g

System kalibreret, tryk Kalibrer for at starte re-kalibrering

Kalibreringsvægt

50g250g1000g

250

Kalibrer

BeeSMART

Din BeeSMART er klar!

Nyd præcis, automatisk honningdosering.

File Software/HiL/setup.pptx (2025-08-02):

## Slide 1

PC

USB-C UART

BeeSMART
Controller

Servo signal

ESP32

Servo (actuator) emulator

Emulator client

Subscribe:
Calculated weight

Publish:
Actuator value

MQTT Broker

HX711 bit stream

Simulator client

HX711 (weight) emulator

Subscribe:
Actuator value

Publish:
Calculated weight

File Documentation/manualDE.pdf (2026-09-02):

# BeeSMART Handbuch

# Wi-Fi gesteuerte Zapf-/Füllmaschine

Version 3.0

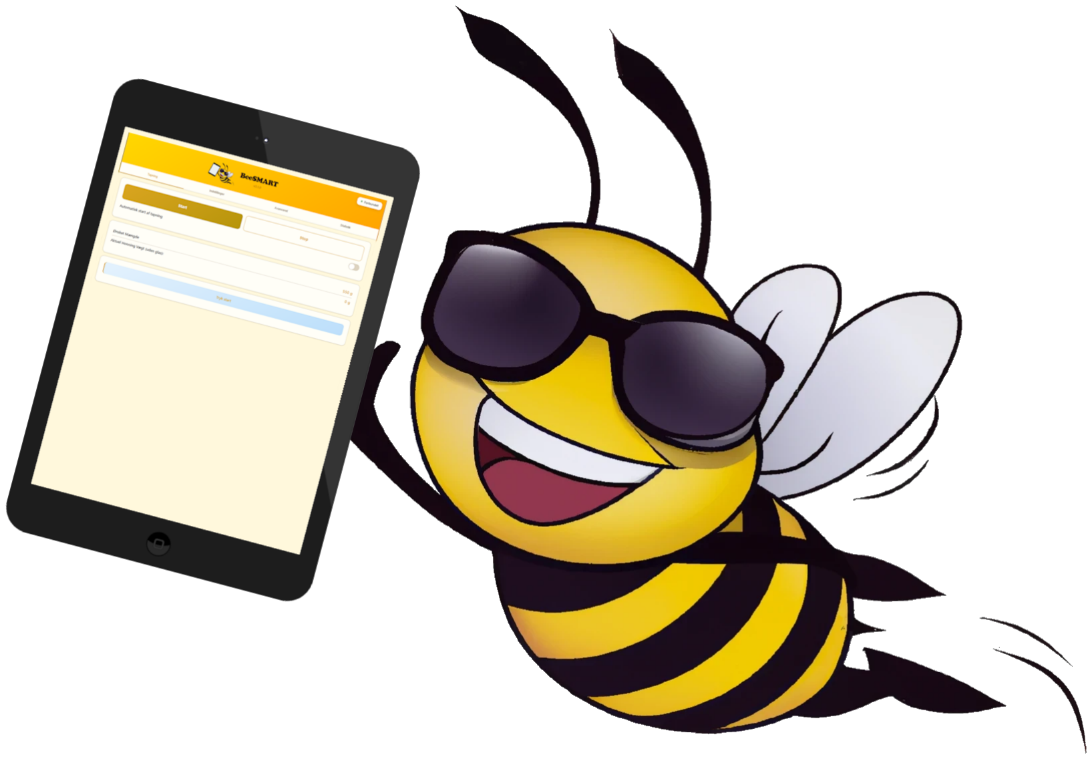
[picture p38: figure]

Entwickelt von Mogens Groth Nicolaisen

Zuletzt aktualisiert: Juni 2026

## Inhaltsverzeichnis

BeeSMART Handbuch | 1 EINFÜHRUNG

### 1 Einführung

BeeSMART ist ein Wi‑Fi‑basiertes Zapfsystem für Honig mit Fokus auf wenige Komponenten, ein‐ fache Bedienung und relativ niedrigen Kosten. Das System kann selbstverständlich auch für andere Flüssigkeiten verwendet werden, bei denen gewichtsbasiertes Befüllen gewünscht ist.

Das System ist browserbasiert und erfordert keine App. Sie greifen über PC, Tablet oder Smartphone darauf zu, sofern das Gerät mit dem BeeSMART‑Wi‑Fi verbunden ist.

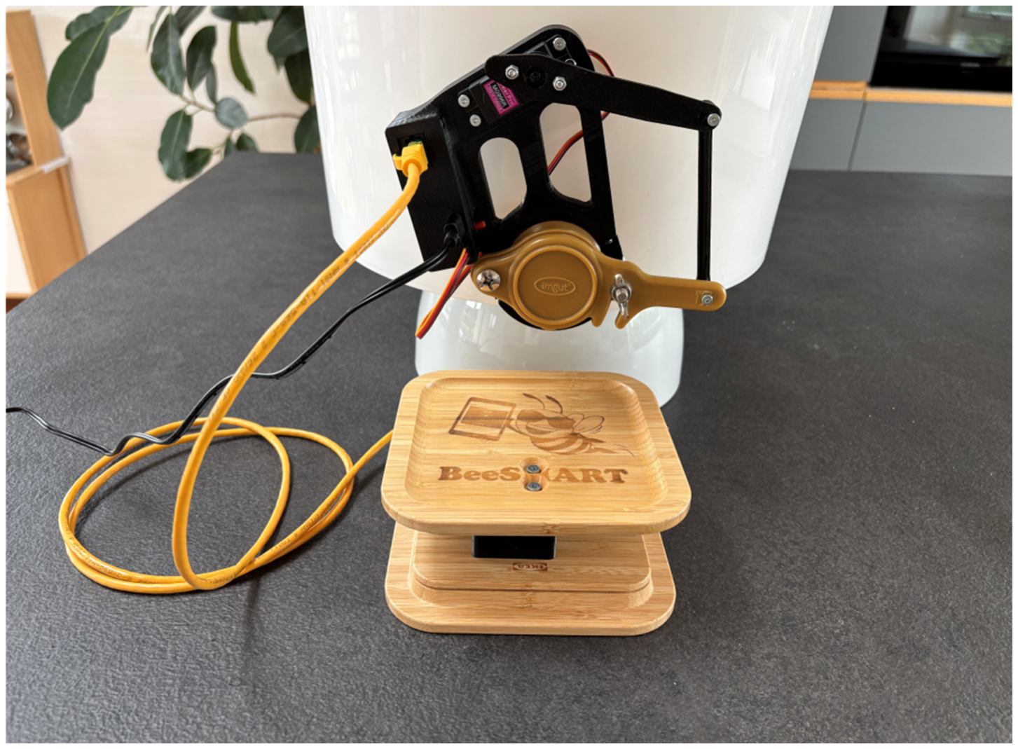
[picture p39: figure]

Das System besteht typischerweise aus:

- BeeSMART Modul mit integrierter Wi‑Fi‑Steuerung und Servo
- Servo‑Horn und Zugstange
- BeeSMART Waage ﴾5 kg﴿
- USB‑C Netzteil
- Montagehalterung und Einsätze für verschiedene Zapfhähne

Die Montagehalterung passt für Zapfhähne mit einem Kragen von ca. 54 mm Durchmesser und mindestens 10 mm Breite. Einsätze für 40 mm Kragen werden mitgeliefert.

BeeSMART Handbuch | 2 STÜCKLISTE

### 2 Stückliste

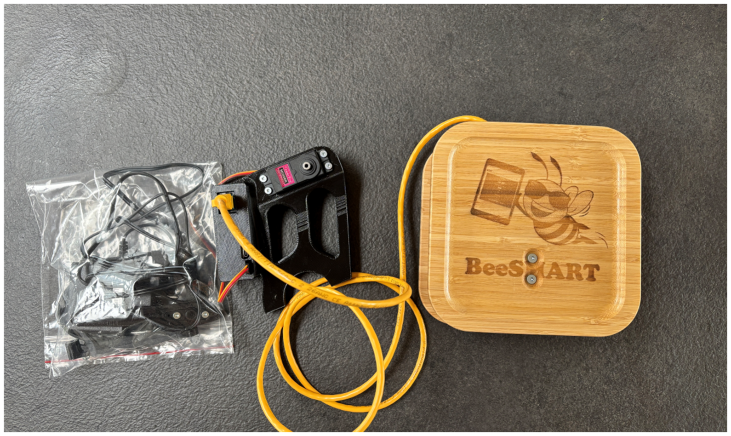
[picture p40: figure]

Standardinhalt eines BeeSMART‑Sets:
Anzahl | Komponente
2 × | M3 selbstsichernde Mutter
2 × | M4 Mutter
1 × | M3 × 16 Schraube
1 × | M3 × 25 Schraube
2 × | M4 × 25 Schraube
1 × | BeeSMART Modul mit Servo und Wi‑Fi‑Steuerung
1 × | Zugstange
1 × | Servo‑Horn, Verlängerung und Schraube
2 × | Einsätze für 40 mm Zapfhahn
1 × | 5 kg BeeSMART Waage
1 × | USB‑C Netzteil

BeeSMART Handbuch | 3 VIDEOMATERIAL

### 3 Videomaterial

Zu BeeSMART gibt es Videomaterial mit:

- Montage und Befestigung von BeeSMART
- Demonstration der Zapffunktionen
- Anwendungsbeispiele mit verschiedenen Einstellungen

Die Videos sind besonders nützlich bei der ersten Einrichtung und zur Feinabstimmung von Servo und Steuerparametern.

# Demo 1

BeeSMART in Betrieb (https://youtu.be/7Y-k81tILdg)

# Demo 2

BeeSMART in Betrieb (https://youtube.com/shorts/xE0CEP3kYTg)

# Demo 3

Erweiterte Funktionen in 3.0 (https://youtu.be/kUqcvOjCH5E)

# Montage

Zapfhahn und Halterung (https://youtu.be/ojsv-gZ6waY)

BeeSMART Handbuch | 4 BEDIENUNGSANLEITUNG

### 4 Bedienungsanleitung

## 4.1 Anschluss und Zugriff

Nach Anschluss von USB‑Stromversorgung, Servo und Waage erstellt BeeSMART einen Wi‑Fi Access Point. Dies sollte innerhalb von ca. 30 Sekunden erfolgen. Falls nicht, drücken Sie kurz die Reset‑Taste am Modul.


Verbinden Sie sich mit dem angezeigten BeeSMART‑Netzwerk von PC, Tablet oder Smartphone. In vielen Fällen öffnet sich automatisch ein Browser mit der BeeSMART‑Benutzeroberfläche. Falls dies nicht geschieht, öffnen Sie den Browser manuell und geben folgende Adresse ein:

beesmart.local

Alternativ kann auch die IP‐Adresse 192.168.4.1 verwendet werden.

BeeSMART Handbuch | 4 BEDIENUNGSANLEITUNG

## 4.2 Hauptbildschirm


Der Hauptbildschirm bietet Übersicht über:

- Gewünschte Menge, die abgefüllt wird ﴾ohne Glas﴿
- Aktuelles Gewicht auf der Waage
- Status‑Text unten, der beschreibt, was das System gerade macht

Die Schaltfläche Start startet einen Zapfvorgang, während Stopp einen laufenden Zapfvorgang unterbricht.

Die Funktion Automatischer Start des Zapfens kann über einen Schalter aktiviert werden. Ist diese aktiviert, startet BeeSMART automatisch einen neuen Zapfvorgang, wenn ein neues leeres Glas auf der Waage erkannt wird.

BeeSMART Handbuch | 4 BEDIENUNGSANLEITUNG

## 4.3 Einstellungen


Auf der Seite Einstellungen können folgende Optionen konfiguriert werden:

- Gewünschte Menge ﴾Honig ohne Glas﴿
- Schließe Hahn, wenn noch X g fehlen
- Glaserkennung: Glas wiegt mehr als
- Maximale Zapfmenge
- Tara ﴾Zurücksetzen der Waage﴿
- Sprachauswahl ﴾z. B. Dänisch, Deutsch, Englisch﴿

Schließe Hahn, wenn noch X g fehlen

Diese Einstellung gibt an, wie viele Gramm vor der gewünschten Menge der Hahn vollständig ge‐ schlossen wird. Sie dient dazu, für Tropfen und die letzte verbleibende Honigmenge nach dem Schließen zu kompensieren.

BeeSMART Handbuch | 4 BEDIENUNGSANLEITUNG

Glaserkennung

Die Grenze für das Glasgewicht gibt an, wie schwer ein leeres Glas mindestens sein muss, um erkannt zu werden. Dies verhindert ein Befüllen ohne Glas auf der Waage.

Maximale Zapfmenge

Dieser Wert erhöht das Maximum des Schiebereglers Gewünschte Menge, wenn größere Mengen abgefüllt werden sollen. Standard‑Maximum, das die Waage handhaben kann, ist 5 kg.

Tara

Tara setzt die Waage zurück. Wird bei leerer Waage verwendet.

BeeSMART Handbuch | 5 ERWEITERT

### 5 Erweitert

Auf der Seite Erweitert können Regelparameter ﴾PID﴿, der Hub des Servos und die Kalibrierung der Waage angepasst werden.


Die Waage ist von Werk aus kalibriert. Eine Neukalibrierung ist normalerweise nur erforderlich, wenn deutliche Abweichungen beobachtet werden.

## 5.1 PID Regelparameter

BeeSMART verwendet PID‑ähnliche Regelparameter, um die Öffnung des Servos in Bezug auf das

gemessene Gewicht zu steuern. Es stehen vordefinierte Viskositätsprofile zur Auswahl:

- Niedrig – für dünneren Honig/Flüssigkeit
- Medium – Standardeinstellung
- Hoch – für sehr zähflüssigen Honig
- Benutzerdefiniert – freie Einstellung von Kp, Ti und Kd

Die Standardwerte, die häufig gut funktionieren, sind:

- Kp = 8

BeeSMART Handbuch | 5 ERWEITERT
- Ti = 7
- Kd = 2

Kp ﴾Proportionaler Anteil﴿

Kp wird mit der Differenz zwischen gewünschtem Gewicht und aktuellem Gewicht im Glas multipli‐ ziert — also mit der fehlenden Menge. Ein kleines Kp führt zu einer kleinen Hahnöffnung, während ein größeres Kp für denselben Fehler eine größere Öffnung bewirkt.

- Größeres Kp bedeutet in der Regel schnelleres Befüllen.
- Zu großes Kp erhöht das Risiko eines Überschreitens der gewünschten Menge.

Ti ﴾Integral/Zeitenkonstante﴿

Ti beschreibt die Geduld des Systems. Ein kleines Ti bedeutet, dass das System schneller auf fehlende Honigmenge reagiert und stärker öffnet. Ein großes Ti führt zu langsameren Reaktionen.

- Kleineres Ti führt zu schnellerer Hochregelung.
- Zu kleines Ti kann zu Überschwingungen und Instabilität führen.

Kd ﴾Differentialanteil﴿

Kd reagiert auf die Geschwindigkeit der Gewichtszunahme. Füllt das Glas sehr schnell, trägt Kd dazu bei, die Servoöffnung vorübergehend zu reduzieren, damit die Füllgeschwindigkeit sinkt. Wenn die Gewichtszunahme wieder kleiner wird, verliert Kd seine Wirkung und der Hahn kann wieder weiter öffnen.

- Zu hohes Kd kann ein öffnen–schließen–öffnen Verhalten verursachen.
- Kd kann nützlich sein, um Überschreitungen zu vermeiden, wenn das Fass sehr voll ist oder der

Honig relativ dünnflüssig ist.

- In der Regel kann Kd oft auf 0 gesetzt werden, es sei denn, eine zusätzliche Dämpfung ist erfor‐ derlich.

Allgemeine Empfehlungen

- Größeres Kp = schnelleres Befüllen, aber größeres Risiko für Überschreiten.
- Kleineres Ti = schnelleres Befüllen, aber größeres Risiko für Überschwingen.
- Kd sollte nur vorsichtig und in kleinen Schritten erhöht werden.

## 5.2 ServoffEinstellung

Auf derselben Seite können Servo Minimum und Servo Maximum eingestellt werden. Es gibt Tasten, um den Servo auf Minimum bzw. Maximum zu fahren, damit die Einstellung getestet werden kann.

BeeSMART Handbuch | 5 ERWEITERT

Einstellung des Servo‑Hubes

1. Entfernen Sie das Servo‑Horn vom Servo.
2. Stellen Sie sicher, dass der Zapfhahn physisch geschlossen ist.
3. Setzen Sie Servo Minimum auf einen geeigneten Wert und fahren Sie den Servo zur Minimalpo‐ sition.
4. Montieren Sie das Servo‑Horn so, dass der Hahn in der Minimalposition gerade geschlossen ist, und ziehen Sie die Schraube fest.
5. Erhöhen Sie Servo Maximum schrittweise, während Sie die Öffnung testen, bis eine passende

Vollöffnung erreicht ist.

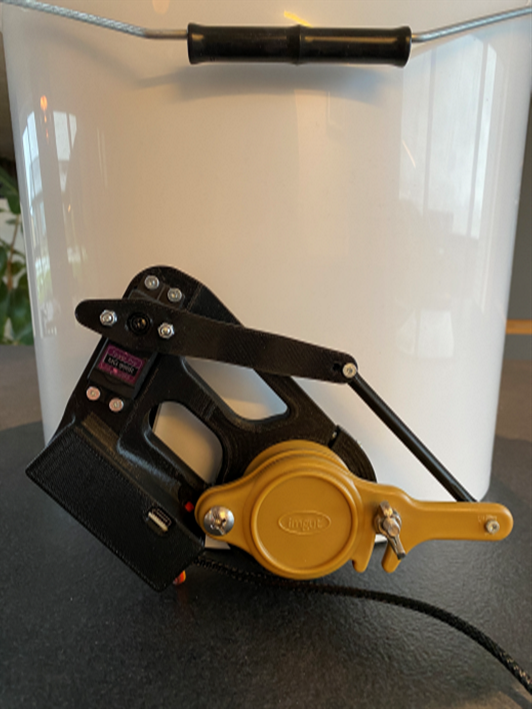
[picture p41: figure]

## 5.3 Waagenkalibrierung

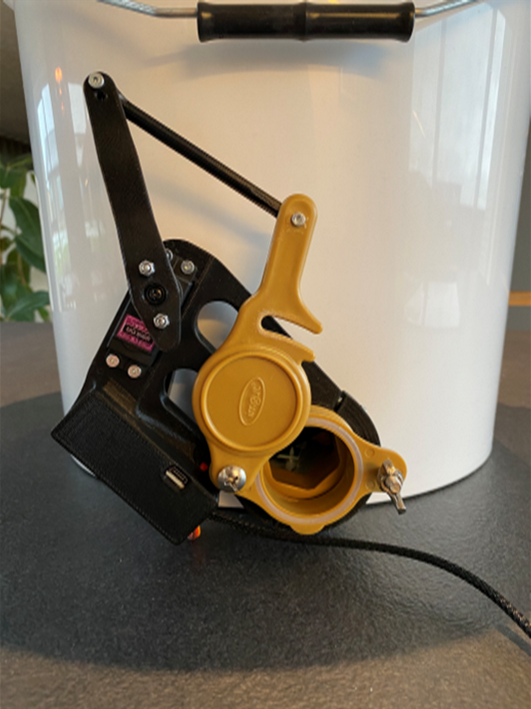
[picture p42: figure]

Die Waage wird kalibriert geliefert. Eine Kalibrierung ist normalerweise nur erforderlich, wenn wie‐ derholt systematische Abweichungen gemessen werden.

Auf der Seite wird ein Kalibrierungsgewicht gewählt ﴾z. B. 50 g, 283 g oder 1000 g﴿, wonach dem Kalibrierungsverfahren gefolgt wird. HINWEIS: Die Waage muss leer sein, wenn Kalibrieren gedrückt wird. Es wird empfohlen, ein möglichst genaues Referenzgewicht zu verwenden.

BeeSMART Handbuch | 6 REGELPARAMETER – DETAILS

### 6 Regelparameter – Details

Die Regelparameter Kp, Ti und Kd arbeiten zusammen, um die Füllgeschwindigkeit zu steuern und sicherzustellen, dass das gewünschte Gewicht so genau wie möglich erreicht wird.

## Beim Anpassen der Parameter

- Beginnen Sie immer mit den Standardwerten.
- Passen Sie jeweils nur einen Parameter an.
- Verwenden Sie die Statistik‑Seite, um die Ergebnisse über mehrere Zapfvorgänge zu bewerten.

## Typische Szenarien

- Wenn die Zapfvorgänge typischerweise unter dem gewünschten Gewicht enden, können Kp oder Ti erhöht werden.
- Wenn häufig zu viel abgefüllt wird, kann Kp verringert und/oder Ti erhöht werden; ggf. kann Kd leicht erhöht werden.
- Bei sehr zähem Honig kann ein größeres Kp erforderlich sein, um einen guten Durchfluss zu er‐ reichen.

BeeSMART Handbuch | 7 STATISTIKEN

### 7 Statistiken

Die Statistik‑Seite gibt einen Überblick darüber, wie genau die Zapfvorgänge im Verhältnis zum

gewünschten Gewicht lagen.


Typischerweise werden angezeigt:

- Gesamte abgefüllte Menge ﴾z. B. in kg﴿
- Anzahl gefüllter Gläser
- Durchschnittliche Abweichung in Gramm
- Diagramm der letzten 10 Zapfvorgänge ﴾gewünscht vs. tatsächlich﴿
- Fehlerverteilung – Anteil von Überschreitungen, Unterschreitungen und perfekten Füllungen

Diese Daten können verwendet werden, um:

- Zu bewerten, ob die Regelparameter passend sind
- Zu erkennen, ob systematisch zu viel oder zu wenig abgefüllt wird
- Die Produktionsdokumentation und Mengenaufzeichnung zu unterstützen

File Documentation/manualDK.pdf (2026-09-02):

# BeeSMART Manual

# Wi-Fi styret tappe-/fyldemaskine

Version 3.0


Udviklet af Mogens Groth Nicolaisen

Senest opdateret: Juni 2026

## Indhold

BeeSMART Manual | 1 INTRODUKTION

### 1 Introduktion

BeeSMART er et Wi‐Fi baseret tappesystem til honning med fokus på få komponenter, enkel betje‐ ning og en relativt lav pris. Systemet kan naturligvis også anvendes til andre væsker, hvor vægtba‐ seret fyldning er ønsket.

Systemet er browserbaseret og kræver ingen app. Du tilgår det via PC, tablet eller smartphone, så længe enheden kan tilsluttes BeeSMARTs Wi‐Fi.

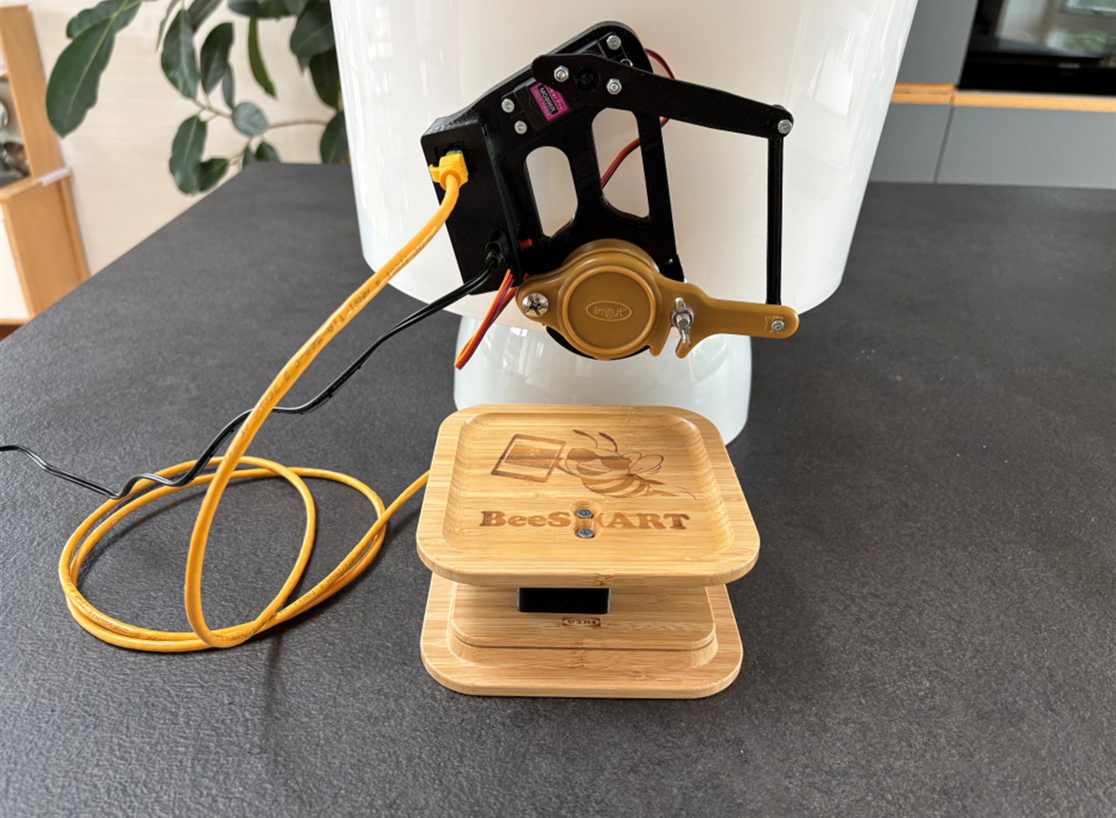
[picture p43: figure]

Systemet består typisk af:

- BeeSMART modul med integreret WiFi‐styring og servo
- Servo horn og trækstang
- BeeSMART vægt ﴾5 kg﴿
- USB‐C strømforsyning
- Monteringsbeslag og indlæg til forskellige tappehaner

Monteringsbeslaget passer til tappehaner med en krave på ca. 54 mm i diameter og mindst 10 mm i bredden. Der medfølger indlæg til 40 mm diameter krave.

BeeSMART Manual | 2 STYKLISTE

### 2 Stykliste


Standardindhold i et BeeSMART sæt:
Antal | Komponent
2 × | M3 selvlåsende møtrik
2 × | M4 møtrik
1 × | M3 × 16 bolt
1 × | M3 × 25 bolt
2 × | M4 × 25 bolt
1 × | BeeSMART modul m. servo og WiFi‐styring
1 × | Trækstang
1 × | Servo horn, forlænger og skrue
2 × | Indlæg til 40 mm tappehane
1 × | 5 kg BeeSMART vægt
1 × | USB‐C strømforsyning

BeeSMART Manual | 3 VIDEO MATERIALE

### 3 Video materiale

Til BeeSMART findes videomateriale med:

- Samling og montering af BeeSMART
- Demonstration af tappefunktioner
- Eksempler på brug med forskellige indstillinger

Videoerne er særligt nyttige ved første opsætning og til finjustering af servo og kontrolparametre.

# Demo 1

BeeSMART i brug (https://youtu.be/7Y-k81tILdg)

# Demo 2

BeeSMART i brug (https://youtube.com/shorts/xE0CEP3kYTg)

# Demo 3

Avancerede funktioner i 3.0 (https://youtu.be/kUqcvOjCH5E)

# Montering

Tappehane og beslag (https://youtu.be/ojsv-gZ6waY)

BeeSMART Manual | 4 BRUGSVEJLEDNING

### 4 Brugsvejledning

## 4.1 Tilslutning og adgang

Efter tilslutning af USB‐strømforsyning, servo og vægt vil BeeSMART oprette et Wi‐Fi Access Point. Dette bør fremkomme inden for ca. 30 sekunder. Hvis ikke, tryk kort på reset‐knappen på modulet.


Tilslut til det viste BeeSMART‐netværk fra PC, tablet eller smartphone. I mange tilfælde åbnes en browser automatisk med BeeSMART‐interfacet. Sker dette ikke, åbnes en browser manuelt, og føl‐ gende adresse indtastes:

beesmart.local

Alternativt kan IP‐adressen 192.168.4.1 også bruges.

BeeSMART Manual | 4 BRUGSVEJLEDNING

## 4.2 Hovedskærm

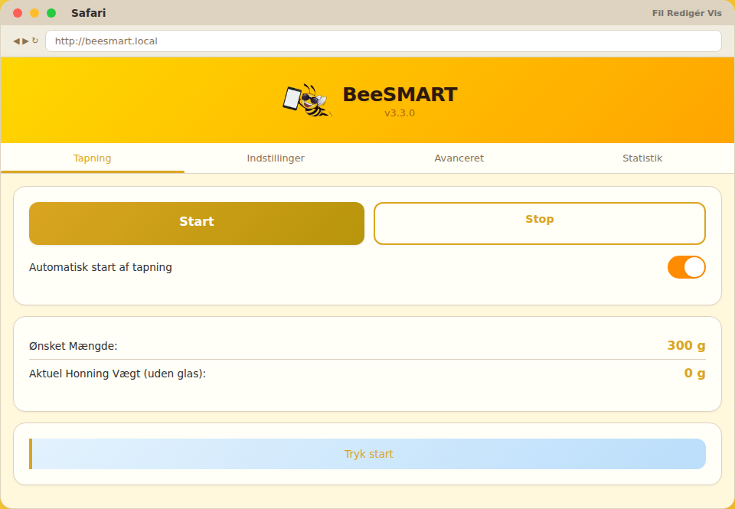
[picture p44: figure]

Hovedskærmen giver overblik over:

- Ønsket mængde, der tappes ﴾uden glas﴿
- Aktuel vægt på vægten
- Status‐tekst nederst, der beskriver hvad systemet gør

Knappen Start starter en tapning, mens Stop afbryder en igangværende tapning.

Funktionen Automatisk start af tapning kan aktiveres via en switch. Når denne er slået til, vil BeeSMART automatisk starte en ny tapning, når et nyt tomt glas registreres på vægten.

BeeSMART Manual | 4 BRUGSVEJLEDNING

## 4.3 Indstillinger

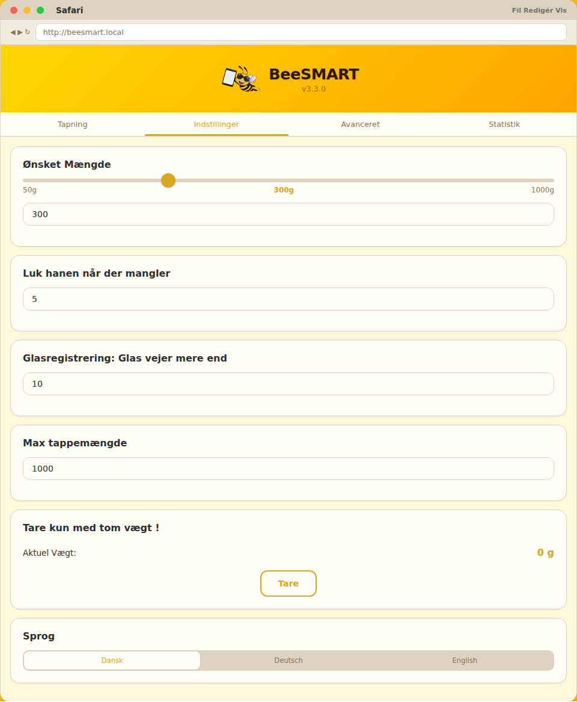
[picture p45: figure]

På Indstillinger‐siden kan følgende konfigureres:

- Ønsket mængde ﴾honning uden glas﴿
- Luk hanen når der mangler X g
- Glasregistrering: Glas vejer mere end
- Max tappemængde
- Tare ﴾nulstilling af vægt﴿
- Sprogvalg ﴾fx Dansk, Deutsch, English﴿

Luk hanen når der mangler X g

Denne indstilling angiver, hvor mange gram før den ønskede mængde, hanen lukkes helt. Den bruges til at kompensere for dryp og den sidste honning, der løber ud efter lukning.

BeeSMART Manual | 4 BRUGSVEJLEDNING

Glasregistrering

Grænsen for glasvægt angiver, hvor tungt et tomt glas mindst skal være, for at blive registreret. Dette forhindrer tapning uden glas på vægten.

Max tappemængde

Denne værdi øger maksimum for slideren Ønsket mængde, hvis der er behov for at tappe større mængder. Standard maksimum som vægten kan håndtere er 5 kg.

Tare

Tare nulstiller vægten. Bruges med tom vægt.

BeeSMART Manual | 5 AVANCERET

### 5 Avanceret

På siden Avanceret kan kontrolparametre ﴾PID﴿, servoens vandring og vægtens kalibrering justeres.

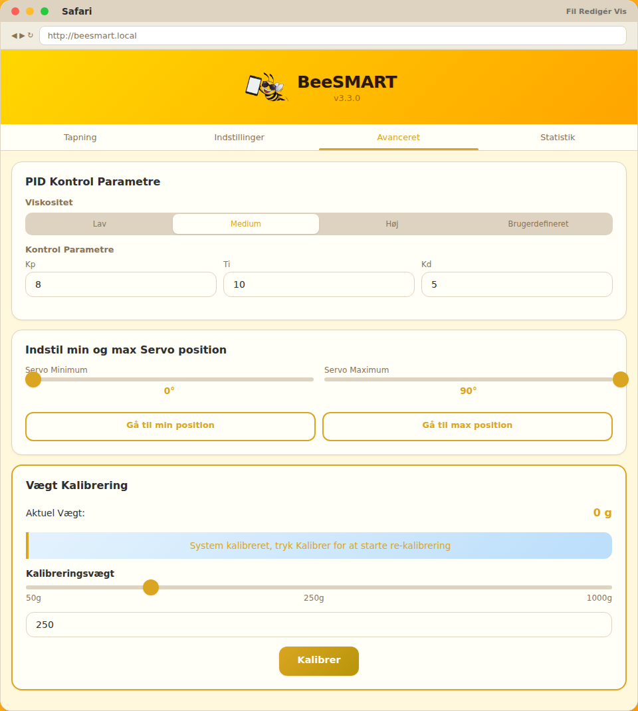
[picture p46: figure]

Vægten er kalibreret fra start, så kalibrering er normalt ikke nødvendig, med mindre der observeres tydelige afvigelser.

## 5.1 PID kontrolparametre

BeeSMART bruger PID‐lignende kontrolparametre til at styre servoens åbning i forhold til den målte vægt. Der kan vælges mellem foruddefinerede viskositetsprofiler:

- Lav – til tyndere honning/væske
- Medium – standardindstilling
- Høj – til meget tyk honning
- Brugerdefineret – fri justering af Kp, Ti og Kd

Standardværdierne, der ofte fungerer godt, er:

- Kp = 8

BeeSMART Manual | 5 AVANCERET
- Ti = 7
- Kd = 2

Kp ﴾Proportionalled﴿

Kp ganges på forskellen mellem den ønskede vægt og den aktuelle vægt i glasset — altså den mængde, der mangler. En lille Kp vil give en lille åbning af tappehanen, mens en større Kp vil give en større åbning for samme fejl.

- Større Kp betyder typisk hurtigere fyldning.
- For stor Kp øger risikoen for at tappe over den ønskede vægt.

Ti ﴾Integral/Tidskonstant﴿

Ti beskriver systemets tålmodighed. En lav Ti betyder, at systemet reagerer hurtigt på, at der mangler honning i glasset, og dermed åbner mere op. En stor Ti betyder omvendt, at systemet reagerer langsommere.

- Mindre Ti giver hurtigere opregulering.
- For lille Ti kan føre til overskydning og ustabilitet.

Kd ﴾Differentialled﴿

Kd reagerer på, hvor hurtigt vægten ændrer sig. Hvis glasset fyldes meget hurtigt, vil Kd bidrage til at reducere servoens åbning midlertidigt, så farten sættes ned. Når vægtændringen igen bliver mindre, vil Kd miste sin effekt, og hanen kan åbne mere igen.

- For høj Kd kan resultere i en åbne–lukke–åbne‐adfærd.
- Kd kan være nyttig for at undgå overskydning, når tønden er helt fuld, eller honningen er relativt tynd.
- Generelt kan Kd ofte sættes til 0, med mindre der er behov for ekstra dæmpning.

Overordnede anbefalinger

- Større Kp = hurtigere fyldning, men større risiko for at komme over ønsket vægt.
- Mindre Ti = hurtigere fyldning, men større risiko for overskydning.
- Kd bør kun øges forsigtigt og ofte kun lidt eller slet ikke.

## 5.2 Servoindstilling

På samme side kan Servo Minimum og Servo Maximum indstilles. Der findes knapper til at køre servoen til henholdsvis min‐ og max‐positionen, så indstillingen kan testes.

BeeSMART Manual | 5 AVANCERET

Indstilling af servo vandring

1. Afmonter servo‐hornet fra servoen.
2. Sørg for, at tappehanen er fysisk lukket.
3. Sæt Servo Minimum til en passende værdi, og kør servoen til min‐position.
4. Monter servo‐hornet, så hanen netop er lukket i min‐position, og spænd skruen.
5. Øg Servo Maximum gradvist, mens du tester åbningsgraden, indtil du finder en passende fuld åbning.


## 5.3 Vægtkalibrering


Vægten leveres kalibreret. Kalibrering er normalt kun nødvendig, hvis der gentagne gange måles systematiske afvigelser.

På siden vælges en kalibreringsvægt ﴾f.eks. 50 g, 283 g eller 1000 g﴿, hvorefter kalibreringsproce‐ duren følges. HUSK ! Vægten skal være tom når der trykkes ”Kalibrer”. Det anbefales at bruge en så præcis referencevægt som muligt.

BeeSMART Manual | 6 KONTROLPARAMETRE – DETALJER

### 6 Kontrolparametre – Detaljer

Kontrolparametrene Kp, Ti og Kd arbejder sammen om at styre tappehastigheden og sikre, at den ønskede vægt rammes så præcist som muligt.

## Når du justerer parametre

- Start altid med standardværdierne.
- Juster kun én parameter ad gangen.
- Brug statistik‐siden til at evaluere resultatet over flere tapninger.

## Typiske scenarier

- Hvis tapningerne typisk ender under den ønskede vægt, kan Kp eller Ti øges.
- Hvis der ofte tappes for meget, kan Kp sænkes, og/eller Ti øges, og eventuelt Kd øges lidt.
- Ved meget tyk honning kan en større Kp være nødvendig for at få en god gennemstrømning.

BeeSMART Manual | 7 STATISTIK

### 7 Statistik

Statistik‐siden giver et overblik over, hvordan tapningerne har ramt i forhold til den ønskede vægt.

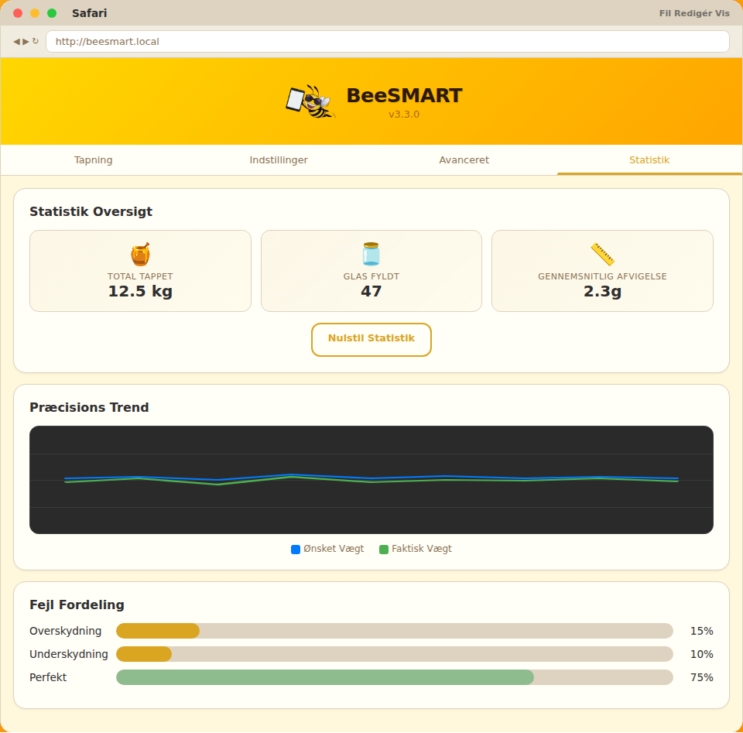
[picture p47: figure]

Typisk vises:

- Total tappet mængde ﴾f.eks. i kg﴿
- Antal glas fyldt
- Gennemsnitlig afvigelse i gram
- Graf over de sidste 10 tapninger ﴾ønsket vs. faktisk vægt﴿
- Fejlfordeling – andel af overskydning, underskydning og perfekt tapning

Disse data kan bruges til at:

- Evaluere om kontrolparametrene er passende
- Finde ud af, om der systematisk tappes for meget eller for lidt
- Understøtte dokumentation af produktion og mængder

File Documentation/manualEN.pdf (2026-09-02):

# BeeSMART Manual

# Wi-Fi controlled tap/fill machine

Version 3.0


Developed by Mogens Groth Nicolaisen

Last updated: June 2026

## Contents

BeeSMART Manual | 1 INTRODUCTION

### 1 Introduction

BeeSMART is a Wi2̆009Fi based honey dispensing system focused on few components, simple op‐ eration and relatively low cost. The system can of course also be used for other liquids where weight‐based filling is desired.

The system is browser‐based and requires no app. Access it from a PC, tablet or smartphone as long as the device can connect to the BeeSMART Wi2̆009Fi.


The system typically consists of:

- BeeSMART module with integrated Wi2̆009Fi control and servo
- Servo horn and pushrod
- BeeSMART scale ﴾5 kg﴿
- USB‐C power supply
- Mounting bracket and inserts for different taps

The mounting bracket fits taps with a collar of about 54 mm diameter and at least 10 mm width. Inserts for 40 mm collars are included.

BeeSMART Manual | 2 PARTS LIST

### 2 Parts List


Contents of a standard BeeSMART kit:
Quantity | Component
2 × | M3 self‐locking nut
2 × | M4 nut
1 × | M3 × 16 screw
1 × | M3 × 25 screw
2 × | M4 × 25 screw
1 × | BeeSMART module with servo and Wi2̆009Fi control
1 × | Pushrod
1 × | Servo horn, extension and screw
2 × | Inserts for 40 mm tap
1 × | 5 kg BeeSMART scale
1 × | USB‐C power supply

BeeSMART Manual | 3 VIDEO MATERIAL

### 3 Video material

There are videos for BeeSMART covering:

- Assembly and mounting of BeeSMART
- Demonstration of dispensing functions
- Usage examples with different settings

The videos are especially useful during initial setup and for fine‐tuning the servo and control pa‐ rameters.

# Demo 1

BeeSMART in use (https://youtu.be/7Y-k81tILdg)

# Demo 2

BeeSMART in use (https://youtube.com/shorts/xE0CEP3kYTg)

# Demo 3

Advanced features in 3.0 (https://youtu.be/kUqcvOjCH5E)

# Mounting

Tap and bracket (https://youtu.be/ojsv-gZ6waY)

BeeSMART Manual | 4 USER GUIDE

### 4 User guide

## 4.1 Connection and access

After connecting USB power, the servo and the scale, BeeSMART will create a Wi2̆009Fi Access Point. This should appear within approximately 30 seconds. If not, briefly press the reset button on the module.


Connect to the displayed BeeSMART network from a PC, tablet or smartphone. In many cases a browser will open automatically with the BeeSMART interface. If this does not happen, open a browser manually and enter the following address:

beesmart.local

Alternatively, the IP address 192.168.4.1 can also be used.

BeeSMART Manual | 4 USER GUIDE

## 4.2 Main screen


The main screen provides an overview of:

- Desired quantity to be dispensed ﴾excluding jar﴿
- Current weight on the scale
- Status text at the bottom describing what the system is doing

The Start button begins a dispense cycle, while Stop interrupts a running dispense.

The Automatic start of dispensing feature can be enabled via a switch. When enabled, BeeSMART will automatically start a new dispense when a new empty jar is detected on the scale.

BeeSMART Manual | 4 USER GUIDE

## 4.3 Settings


On the Settings page you can configure:

- Desired quantity ﴾honey without jar﴿
- Close tap when X g remain
- Jar detection: Jar weighs more than
- Max dispense quantity
- Tare ﴾reset scale﴿
- Language selection ﴾e.g. Danish, German, English﴿

Close tap when X g remain

This setting specifies how many grams before the desired quantity the tap is fully closed. It com‐ pensates for dripping and the last honey remaining after closing.

BeeSMART Manual | 4 USER GUIDE

Jar detection

The jar weight threshold sets how heavy an empty jar must be to be detected. This prevents dis‐ pensing without a jar on the scale.

Max dispense quantity

This value increases the maximum of the Desired quantity slider if larger fills are needed. The default maximum the scale can handle is 5 kg.

Tare

Tare resets the scale. Use with an empty scale.

BeeSMART Manual | 5 ADVANCED

### 5 Advanced

On the Advanced page you can adjust control parameters ﴾PID﴿, the servo travel and the scale cali‐ bration.


The scale is calibrated at the factory. Calibration is normally not required unless significant devia‐ tions are observed.

## 5.1 PID control parameters

BeeSMART uses PID‐like control parameters to control servo opening relative to measured weight. Predefined viscosity profiles are available:

- Low – for thinner honey/liquid
- Medium – default
- High – for very thick honey
- Custom – free adjustment of Kp, Ti and Kd

Typical default values that often work well are:

- Kp = 8

BeeSMART Manual | 5 ADVANCED
- Ti = 7
- Kd = 2

Kp ﴾Proportional﴿

Kp is multiplied by the difference between desired weight and current weight in the jar — i.e. the missing amount. A small Kp yields a small tap opening, while a larger Kp yields a larger opening for the same error.

- Larger Kp typically means faster filling.
- Too large Kp increases the risk of overfilling.

Ti ﴾Integral/time constant﴿

Ti describes the system’s patience. A small Ti means the system reacts quickly to missing honey and opens more. A large Ti causes slower reactions.

- Smaller Ti leads to faster correction.
- Too small Ti can cause overshoot and instability.

Kd ﴾Derivative﴿

Kd reacts to how fast the weight is changing. If the jar fills very fast, Kd helps temporarily reduce servo opening so the rate slows. When the weight change becomes smaller again, Kd loses effect and the tap can open more.

- Too high Kd can cause an open–close–open behavior.
- Kd can help avoid overshoot when the source is nearly empty or the honey is relatively thin.
- Generally Kd can often be set to 0 unless extra damping is needed.

General recommendations

- Larger Kp = faster filling, but higher risk of overshoot.
- Smaller Ti = faster filling, but higher risk of overshoot.
- Increase Kd only cautiously and in small steps.

## 5.2 Servo setup

On the same page you can set Servo Minimum and Servo Maximum. Buttons are provided to move the servo to min and max positions for testing.

Setting servo travel

1. Remove the servo horn from the servo.
2. Ensure the tap is physically closed.

BeeSMART Manual | 5 ADVANCED
3. Set Servo Minimum to a suitable value and move the servo to the min position.
4. Mount the servo horn so the tap is just closed in the min position and tighten the screw.
5. Increase Servo Maximum gradually while testing the opening until a suitable full opening is reached.


## 5.3 Scale calibration


The scale is delivered calibrated. Calibration is normally only necessary if systematic deviations are repeatedly observed.

On the page select a calibration weight ﴾e.g. 50 g, 283 g or 1000 g﴿ and follow the calibration procedure. NOTE: The scale must be empty when pressing ”Calibrate”. Use a as‐accurate reference weight as possible.

BeeSMART Manual | 6 CONTROL PARAMETERS — DETAILS

### 6 Control parameters — Details

The control parameters Kp, Ti and Kd work together to control fill speed and ensure the desired weight is reached as accurately as possible.

## When adjusting parameters

- Always start from the default values.
- Adjust only one parameter at a time.
- Use the Statistics page to evaluate results over multiple fills.

## Typical scenarios

- If fills typically end below the desired weight, increase Kp or Ti.
- If often overfilled, decrease Kp and/or increase Ti; consider slightly increasing Kd.
- Very thick honey may require larger Kp to maintain good flow.

BeeSMART Manual | 7 STATISTICS

### 7 Statistics

The Statistics page provides an overview of how fills performed relative to the desired weight.


Typically shown:

- Total dispensed volume ﴾e.g. in kg﴿
- Number of jars filled
- Average deviation in grams
- Graph of last 10 fills ﴾desired vs actual﴿
- Error distribution — share of overfills, underfills and perfect fills

These data can be used to:

- Evaluate if control parameters are suitable
- Identify systematic overfilling or underfilling
- Support production documentation and quantity tracking

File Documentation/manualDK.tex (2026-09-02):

% ======================================================================
% BeeSMART Manual (Print-Optimized LaTeX Version)
% Style B — Clean, professional, BeeSMART color palette + fonts
% ======================================================================

\documentclass[11pt,a4paper]{article}

% ---------------------------------------------------------
% Packages
% ---------------------------------------------------------
\usepackage{fontspec}
\usepackage{titlesec}
\usepackage{graphicx}
\usepackage{geometry}
\usepackage{setspace}
\usepackage{hyperref}
\usepackage{xcolor}
\usepackage{tocloft}
\usepackage{parskip}
\usepackage{fancyhdr}
\usepackage{enumitem}
\usepackage[danish]{babel}
\usepackage[table]{xcolor}
\usepackage{qrcode}

% ---------------------------------------------------------
% Page Setup
% ---------------------------------------------------------
\geometry{
    a4paper,
    margin=2.2cm
}

\setstretch{1.25}

% ---------------------------------------------------------
% BeeSMART Color Palette (translated from CSS)
% ---------------------------------------------------------
\definecolor{primary}{HTML}{DAA520}        % Golden Rod
\definecolor{primarylight}{HTML}{F4D03F}   % Light golden
\definecolor{primarydark}{HTML}{B7950B}    % Dark golden
\definecolor{secondary}{HTML}{FF8C00}      % Dark orange
\definecolor{accent}{HTML}{FFE135}         % Bright yellow
\definecolor{success}{HTML}{8FBC8F}        % Muted green
\definecolor{destructive}{HTML}{CD853F}    % Peru
\definecolor{warning}{HTML}{F0E68C}        % Khaki
\definecolor{textprimary}{HTML}{2F2F2F}    % Dark gray
\definecolor{textsecondary}{HTML}{8B7355}  % Warm brown-gray
\definecolor{separator}{HTML}{DDD3C0}      % Beige

% ---------------------------------------------------------
% Fonts (Cooper Black + Fredoka One)
% ---------------------------------------------------------
\setmainfont{Segoe UI}[
    Ligatures=TeX
]

\newfontfamily\cooper{Cooper Black}
\newfontfamily\fredoka{Fredoka One}

% ---------------------------------------------------------
% Heading Styles
% ---------------------------------------------------------
\titleformat{\section}
  {\large\bfseries\cooper\color{primarydark}}
  {\thesection}{1em}{}

\titleformat{\subsection}
  {\normalsize\bfseries\fredoka\color{secondary}}
  {\thesubsection}{1em}{}

\titleformat{\subsubsection}
  {\normalsize\bfseries\color{textprimary}}
  {\thesubsubsection}{1em}{}

% ---------------------------------------------------------
% Table of Contents Styling
% ---------------------------------------------------------
\renewcommand{\cftsecleader}{\cftdotfill{\cftdotsep}}

% ---------------------------------------------------------
% Hyperlink Colors
% ---------------------------------------------------------
\hypersetup{
    colorlinks=true,
    linkcolor=primarydark,
    urlcolor=secondary
}

% ---------------------------------------------------------
% Headers and Footers
% ---------------------------------------------------------
\pagestyle{fancy}
\fancyhf{} % clear all
\lhead{\textcolor{textsecondary}{BeeSMART Manual}}
\rhead{\textcolor{textsecondary}{\leftmark}}
\cfoot{\textcolor{textsecondary}{\thepage}}
\renewcommand{\headrulewidth}{0.4pt}
\renewcommand{\headrule}{\hbox to\headwidth{\color{separator}\leaders\hrule height \headrulewidth\hfill}}
\renewcommand{\footrulewidth}{0pt}

% ---------------------------------------------------------
% Document Start
% ---------------------------------------------------------
\begin{document}

% ---------------------------------------------------------
% Cover Page
% ---------------------------------------------------------
\begin{titlepage}
    \centering
    {\cooper\fontsize{28}{32}\selectfont BeeSMART Manual}\\[1.5em]
    {\fredoka\Large Wi-Fi styret tappe-/fyldemaskine}\\[1em]
    {\large Version 3.0}\\[3em]

    \\[3em]

    {\small Udviklet af Mogens Groth Nicolaisen}\\
    {\small Senest opdateret: Juni 2026}

\end{titlepage}

\newpage

% ---------------------------------------------------------
% Table of Contents
% ---------------------------------------------------------
\tableofcontents
\newpage

% ---------------------------------------------------------
% 1. Introduktion
% ---------------------------------------------------------
\section{Introduktion}

BeeSMART er et Wi-Fi baseret tappesystem til honning med fokus på få komponenter, enkel betjening og en relativt lav pris. Systemet kan naturligvis også anvendes til andre væsker, hvor vægtbaseret fyldning er ønsket.

Systemet er browserbaseret og kræver ingen app. Du tilgår det via PC, tablet eller smartphone, så længe enheden kan tilsluttes BeeSMARTs Wi-Fi.

\begin{center}

\end{center}

Systemet består typisk af:
\begin{itemize}[leftmargin=*]
    \item BeeSMART modul med integreret WiFi-styring og servo
    \item Servo horn og trækstang
    \item BeeSMART vægt (5 kg)
    \item USB-C strømforsyning
    \item Monteringsbeslag og indlæg til forskellige tappehaner
\end{itemize}

Monteringsbeslaget passer til tappehaner med en krave på ca. 54 mm i diameter og mindst 10 mm i bredden. Der medfølger indlæg til 40 mm diameter krave.

\newpage

% ---------------------------------------------------------
% 2. Stykliste
% ---------------------------------------------------------
\section{Stykliste}

\begin{center}

\end{center}

Standardindhold i et BeeSMART sæt:

\begin{center}
	\renewcommand{\arraystretch}{1.3}
	
	\begin{tabular}{ll}
		\rowcolor{primarylight!40}
		{\fredoka\textbf{Antal}} & {\fredoka\textbf{Komponent}} \\
		
		\rowcolor{primarylight!15}
		2 × & M3 selvlåsende møtrik \\
		
		\rowcolor{primarylight!5}
		2 × & M4 møtrik \\
		
		\rowcolor{primarylight!15}
		1 × & M3 × 16 bolt \\
		
		\rowcolor{primarylight!5}
		1 × & M3 × 25 bolt \\
		
		\rowcolor{primarylight!15}
		2 × & M4 × 25 bolt \\
		
		\rowcolor{primarylight!5}
		1 × & BeeSMART modul m. servo og WiFi-styring \\
		
		\rowcolor{primarylight!15}
		1 × & Trækstang \\
		
		\rowcolor{primarylight!5}
		1 × & Servo horn, forlænger og skrue \\
		
		\rowcolor{primarylight!15}
		2 × & Indlæg til 40 mm tappehane \\
		
		\rowcolor{primarylight!5}
		1 × & 5 kg BeeSMART vægt \\
		
		\rowcolor{primarylight!15}
		1 × & USB-C strømforsyning \\
		
	\end{tabular}
\end{center}
\newpage

% ---------------------------------------------------------
% 3. Video materiale
% ---------------------------------------------------------
\section{Video materiale}

Til BeeSMART findes videomateriale med:

\begin{itemize}[leftmargin=*]
    \item Samling og montering af BeeSMART
    \item Demonstration af tappefunktioner
    \item Eksempler på brug med forskellige indstillinger
\end{itemize}

\vspace{2em}
Videoerne er særligt nyttige ved første opsætning og til finjustering af servo og kontrolparametre.
\vspace{2em}

\begin{center}
	\begin{tabular}{cc}
		
		% ------------------ Row 1, Col 1 ------------------
		\begin{minipage}{0.45\textwidth}
			\centering
			\qrcode[height=3.5cm]{https://youtu.be/7Y-k81tILdg}\\[0.3em]
			
			\href{https://youtu.be/7Y-k81tILdg}{%
				{\fredoka\color{primarydark}\Large Demo 1}%
			}\\[-0.2em]
			
			\href{https://youtu.be/7Y-k81tILdg}{%
				{\small BeeSMART i brug}%
			}
		\end{minipage}
		&
		% ------------------ Row 1, Col 2 ------------------
		\begin{minipage}{0.45\textwidth}
			\centering
			\qrcode[height=3.5cm]{https://youtube.com/shorts/xE0CEP3kYTg}\\[0.3em]
			
			\href{https://youtube.com/shorts/xE0CEP3kYTg}{%
				{\fredoka\color{primarydark}\Large Demo 2}%
			}\\[-0.2em]
			
			\href{https://youtube.com/shorts/xE0CEP3kYTg}{%
				{\small BeeSMART i brug}%
			}
		\end{minipage}
		
		\\[8em]
		
		% ------------------ Row 2, Col 1 ------------------
		\begin{minipage}{0.45\textwidth}
			\centering
			\qrcode[height=3.5cm]{https://youtu.be/kUqcvOjCH5E}\\[0.3em]
			
			\href{https://youtu.be/kUqcvOjCH5E}{%
				{\fredoka\color{primarydark}\Large Demo 3}%
			}\\[-0.2em]
			
			\href{https://youtu.be/kUqcvOjCH5E}{%
				{\small Avancerede funktioner i 3.0}%
			}
		\end{minipage}
		&
		% ------------------ Row 2, Col 2 ------------------
		\begin{minipage}{0.45\textwidth}
			\centering
			\qrcode[height=3.5cm]{https://youtu.be/ojsv-gZ6waY}\\[0.3em]
			
			\href{https://youtu.be/ojsv-gZ6waY}{%
				{\fredoka\color{primarydark}\Large Montering}%
			}\\[-0.2em]
			
			\href{https://youtu.be/ojsv-gZ6waY}{%
				{\small Tappehane og beslag}%
			}
		\end{minipage}
		
	\end{tabular}
\end{center}

\newpage

% ---------------------------------------------------------
% 4. Brugsvejledning
% ---------------------------------------------------------
\section{Brugsvejledning}

\subsection{Tilslutning og adgang}

Efter tilslutning af USB-strømforsyning, servo og vægt vil BeeSMART oprette et Wi-Fi Access Point. Dette bør fremkomme inden for ca. 30 sekunder. Hvis ikke, tryk kort på reset-knappen på modulet.

\begin{center}

\end{center}

Tilslut til det viste BeeSMART-netværk fra PC, tablet eller smartphone. I mange tilfælde åbnes en browser automatisk med BeeSMART-interfacet. Sker dette ikke, åbnes en browser manuelt, og følgende adresse indtastes:

\begin{verbatim}
beesmart.local
\end{verbatim}

\noindent Alternativt kan IP-adressen \texttt{192.168.4.1} også bruges.

\subsection{Hovedskærm}

\begin{center}

\end{center}

Hovedskærmen giver overblik over:

\begin{itemize}[leftmargin=*]
    \item Ønsket mængde, der tappes (uden glas)
    \item Aktuel vægt på vægten
    \item Status-tekst nederst, der beskriver hvad systemet gør
\end{itemize}

Knappen \textbf{Start} starter en tapning, mens \textbf{Stop} afbryder en igangværende tapning.

Funktionen \textbf{Automatisk start af tapning} kan aktiveres via en switch. Når denne er slået til, vil BeeSMART automatisk starte en ny tapning, når et nyt tomt glas registreres på vægten.

\subsection{Indstillinger}

\begin{center}

\end{center}

På \textit{Indstillinger}-siden kan følgende konfigureres:

\begin{itemize}[leftmargin=*]
    \item \textbf{Ønsket mængde} (honning uden glas)
    \item \textbf{Luk hanen når der mangler X g}
    \item \textbf{Glasregistrering: Glas vejer mere end}
    \item \textbf{Max tappemængde}
    \item \textbf{Tare} (nulstilling af vægt)
    \item \textbf{Sprogvalg} (fx Dansk, Deutsch, English)
\end{itemize}

\subsubsection*{Luk hanen når der mangler X g}

Denne indstilling angiver, hvor mange gram før den ønskede mængde, hanen lukkes helt. Den bruges til at kompensere for \textit{dryp} og den sidste honning, der løber ud efter lukning.

\subsubsection*{Glasregistrering}

Grænsen for glasvægt angiver, hvor tungt et tomt glas mindst skal være, for at blive registreret. Dette forhindrer tapning uden glas på vægten.

\subsubsection*{Max tappemængde}

Denne værdi øger maksimum for slideren \textit{Ønsket mængde}, hvis der er behov for at tappe større mængder. Standard maksimum som vægten kan håndtere er 5 kg.

\subsubsection*{Tare}

\textbf{Tare} nulstiller vægten. Bruges med tom vægt.

\newpage

% ---------------------------------------------------------
% 5. Avanceret
% ---------------------------------------------------------
\section{Avanceret}

På siden \textit{Avanceret} kan kontrolparametre (PID), servoens vandring og vægtens kalibrering justeres.

\begin{center}

\end{center}

Vægten er kalibreret fra start, så kalibrering er normalt ikke nødvendig, med mindre der observeres tydelige afvigelser.

\subsection{PID kontrolparametre}

BeeSMART bruger PID-lignende kontrolparametre til at styre servoens åbning i forhold til den målte vægt. Der kan vælges mellem foruddefinerede viskositetsprofiler:

\begin{itemize}[leftmargin=*]
    \item \textbf{Lav} – til tyndere honning/væske
    \item \textbf{Medium} – standardindstilling
    \item \textbf{Høj} – til meget tyk honning
    \item \textbf{Brugerdefineret} – fri justering af Kp, Ti og Kd
\end{itemize}

Standardværdierne, der ofte fungerer godt, er:
\begin{itemize}[leftmargin=*]
    \item Kp = 8
    \item Ti = 7
    \item Kd = 2
\end{itemize}

\subsubsection*{Kp (Proportionalled)}

Kp ganges på forskellen mellem den ønskede vægt og den aktuelle vægt i glasset — altså den mængde, der mangler. En lille Kp vil give en lille åbning af tappehanen, mens en større Kp vil give en større åbning for samme fejl.

\begin{itemize}[leftmargin=*]
    \item Større Kp betyder typisk hurtigere fyldning.
    \item For stor Kp øger risikoen for at tappe over den ønskede vægt.
\end{itemize}

\subsubsection*{Ti (Integral/Tidskonstant)}

Ti beskriver systemets \textit{tålmodighed}. En lav Ti betyder, at systemet reagerer hurtigt på, at der mangler honning i glasset, og dermed åbner mere op. En stor Ti betyder omvendt, at systemet reagerer langsommere.

\begin{itemize}[leftmargin=*]
    \item Mindre Ti giver hurtigere opregulering.
    \item For lille Ti kan føre til overskydning og ustabilitet.
\end{itemize}

\subsubsection*{Kd (Differentialled)}

Kd reagerer på, hvor hurtigt vægten ændrer sig. Hvis glasset fyldes meget hurtigt, vil Kd bidrage til at reducere servoens åbning midlertidigt, så farten sættes ned. Når vægtændringen igen bliver mindre, vil Kd miste sin effekt, og hanen kan åbne mere igen.

\begin{itemize}[leftmargin=*]
    \item For høj Kd kan resultere i en \textit{åbne–lukke–åbne}-adfærd.
    \item Kd kan være nyttig for at undgå overskydning, når tønden er helt fuld, eller honningen er relativt tynd.
    \item Generelt kan Kd ofte sættes til 0, med mindre der er behov for ekstra dæmpning.
\end{itemize}

\subsubsection*{Overordnede anbefalinger}

\begin{itemize}[leftmargin=*]
    \item Større Kp = hurtigere fyldning, men større risiko for at komme over ønsket vægt.
    \item Mindre Ti = hurtigere fyldning, men større risiko for overskydning.
    \item Kd bør kun øges forsigtigt og ofte kun lidt eller slet ikke.
\end{itemize}

\subsection{Servoindstilling}

På samme side kan \textit{Servo Minimum} og \textit{Servo Maximum} indstilles. Der findes knapper til at køre servoen til henholdsvis min- og max-positionen, så indstillingen kan testes.

\subsubsection*{Indstilling af servo vandring}

\begin{enumerate}[leftmargin=*]
    \item Afmonter servo-hornet fra servoen.
    \item Sørg for, at tappehanen er fysisk lukket.
    \item Sæt \textit{Servo Minimum} til en passende værdi, og kør servoen til min-position.
    \item Monter servo-hornet, så hanen netop er lukket i min-position, og spænd skruen.
    \item Øg \textit{Servo Maximum} gradvist, mens du tester åbningsgraden, indtil du finder en passende fuld åbning.
\end{enumerate}

\begin{center}
	\begin{minipage}{0.45\textwidth}
		\centering
		
	\end{minipage}
	\hfill
	\begin{minipage}{0.45\textwidth}
		\centering
		
	\end{minipage}
\end{center}

\subsection{Vægtkalibrering}

Vægten leveres kalibreret. Kalibrering er normalt kun nødvendig, hvis der gentagne gange måles systematiske afvigelser.

På siden vælges en kalibreringsvægt (f.eks. 50 g, 283 g eller 1000 g), hvorefter kalibreringsproceduren følges. HUSK ! Vægten skal være tom når der trykkes "Kalibrer". Det anbefales at bruge en så præcis referencevægt som muligt.

\newpage

% ---------------------------------------------------------
% 6. Kontrolparametre – Detaljer
% ---------------------------------------------------------
\section{Kontrolparametre – Detaljer}

Kontrolparametrene Kp, Ti og Kd arbejder sammen om at styre tappehastigheden og sikre, at den ønskede vægt rammes så præcist som muligt.

\subsection*{Når du justerer parametre}

\begin{itemize}[leftmargin=*]
    \item Start altid med standardværdierne.
    \item Juster kun én parameter ad gangen.
    \item Brug statistik-siden til at evaluere resultatet over flere tapninger.
\end{itemize}

\subsection*{Typiske scenarier}

\begin{itemize}[leftmargin=*]
    \item Hvis tapningerne typisk ender under den ønskede vægt, kan Kp eller Ti øges.
    \item Hvis der ofte tappes for meget, kan Kp sænkes, og/eller Ti øges, og eventuelt Kd øges lidt.
    \item Ved meget tyk honning kan en større Kp være nødvendig for at få en god gennemstrømning.
\end{itemize}

\newpage

% ---------------------------------------------------------
% 7. Statistik
% ---------------------------------------------------------
\section{Statistik}

Statistik-siden giver et overblik over, hvordan tapningerne har ramt i forhold til den ønskede vægt.

\begin{center}

\end{center}

Typisk vises:

\begin{itemize}[leftmargin=*]
    \item \textbf{Total tappet mængde} (f.eks. i kg)
    \item \textbf{Antal glas fyldt}
    \item \textbf{Gennemsnitlig afvigelse} i gram
    \item \textbf{Graf over de sidste 10 tapninger} (ønsket vs. faktisk vægt)
    \item \textbf{Fejlfordeling} – andel af overskydning, underskydning og \textit{perfekt} tapning
\end{itemize}

Disse data kan bruges til at:

\begin{itemize}[leftmargin=*]
    \item Evaluere om kontrolparametrene er passende
    \item Finde ud af, om der systematisk tappes for meget eller for lidt
    \item Understøtte dokumentation af produktion og mængder
\end{itemize}

\end{document}

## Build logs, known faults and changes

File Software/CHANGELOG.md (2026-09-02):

# Changelog

## v3.3.0

### Improvements

- **Modular project structure** — Monolithic 1462-line `.ino` file split into `src/` modules:
  `globals`, `filesystem`, `statistics`, `control`, `webserver`. The `.ino` entry point
  is now 134 lines (setup + loop only).
- **WebSocket broadcast tiers** — Lightweight weight-only JSON (25 Hz) replaces full
  status broadcasts every loop cycle. Full status (including statistics) broadcasts
  once per second, reducing browser parsing load.
- **Immediate auto-off on stop** — Pressing the Stop button now immediately unchecks the
  "Auto Start" toggle locally, eliminating the 10-second polling delay.
- **WebP logo** — `beesmart_bee.png` (521 KB) compressed to `beesmart_bee.webp` (62 KB)
  using quality 80, reducing the LittleFS data directory from 640 KB to 188 KB.
- **Immediate viscosity PID update** — Changing the viscosity preset now calls
  `fetchSettings()` immediately, eliminating the 10-second delay for PID field updates
  in the UI.
- **LittleFS image builder** — `build_merge.bat` builds the filesystem image from the
  `data/` directory. Flash it at offset `0x290000`.

### Bug Fixes

- **Stop button does not toggle auto start off** — The client-side stop handler now
  immediately sets `autoState = false` and updates the toggle, and the WebSocket
  handler syncs `autoState` from incoming data for consistency.
- **Input validation regressions** — Restored `setAmount` clamping to `[minWeight, maxWeight]`,
  `setLanguage` range constraint to 0–2, and `start` command now checks `calStateMachine == 0`.
- **Unknown API commands return 400** — Unknown commands no longer silently return success.
- **Slider snap-back race condition** — Debounced slider commands are tracked; settings
  updates from the server skip fields with pending local changes. Slider values are not
  overwritten while the user is dragging (focus-aware).

## v3.2.0

### Bug Fixes

- **Number input fields no longer revert while typing** — The settings polling loop
  previously overwrote input fields every 2 seconds, causing user input to be lost.
  Fields that have focus are now skipped during UI updates.
- **Slider snap-back fixed** — Servo position sliders no longer jump back to stale
  values while the user is dragging them. Settings with pending commands are skipped
  during polling updates.
- **Ti=0 division by zero in PID** — The high-viscosity preset sets Ti=0; the integral
  gain calculation now guards against division by zero.
- **CSV parsing bug for PID presets 1–3** — A substring index error caused kP values for
  presets 1–3 to include a leading comma, parsing to 0. Fixed the start-index logic.
- **Division by zero when idle** — `adjustedWeight / setpoint` in the main loop now
  guards against setpoint=0.
- **API input validation** — `gainSelector` is clamped to 0–3, `lang` to 0–2,
  `calWeight` minimum enforced at 1, `maxWeight` clamped to valid range.
  `deserializeJson` return value is now checked with a 400 error response on failure.
- **snprintf buffer overflow** — WiFi SSID buffer increased to 26 bytes with `sizeof()`
  used for safety.
- **Hardcoded Danish string** — Calibration step 2 text now uses the translation array
  `calStep2Text[lang]` instead of a hardcoded Danish string.
- **Settings polling interval leak** — The `setInterval` ID is now properly stored and
  cleared before creating a new interval, preventing memory leaks when switching tabs.
- **setpointPI normalisation** — Fixed `setpointPI = setpoint / setpoint` (always 1.0)
  to use the correct normalised value.

### New Features

- **mDNS hostname** — The device now advertises itself as `beesmart.local` via mDNS.
  Users can type `beesmart.local` in a browser instead of `192.168.4.1`.
- **Captive portal improvement** — Unknown host requests are served the UI page directly
  instead of issuing a redirect, improving compatibility with mobile captive portal
  browsers.
- **Glass detection filter** — A 2-second millis()-based filter ensures the glass is
  stably on the scale before the filling process starts, preventing false triggers.
- **Max tapping amount increased** — The maximum allowable weight is now 25,000 g (was
  20,000 g). Default remains 1,000 g.
- **Servo button highlighting** — The "Go to Min" / "Go to Max" servo buttons now
  maintain a highlighted state showing which position was last selected. "Go to Min"
  is highlighted by default on page load.

### Improvements

- **Slider HTTP debounce** — Slider value changes are debounced (250 ms) before sending
  HTTP requests, reducing network load by ~95% during slider drags.
- **server.handleClient() timing** — HTTP request handling moved outside the 20 ms timer
  gate for more responsive web UI.
- **Blocking delay removed** — The 100 ms `delay()` call after file writes has been
  removed; `file.close()` is already synchronous.
- **Cache-Control headers** — CSS and JS responses include `Cache-Control: no-cache` to
  prevent stale cached assets after firmware updates.

## v3.1.0

- Initial public release of honeyDosing v3.

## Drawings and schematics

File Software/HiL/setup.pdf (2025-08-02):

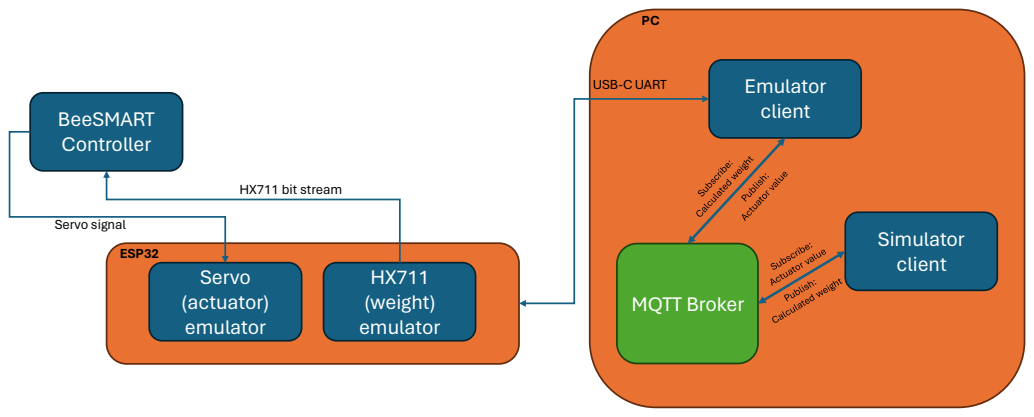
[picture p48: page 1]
MQTT Broker; BeeSMART Controller; HX711 (weight) emulator; Servo (actuator) emulator; Simulator client; Servo signal; HX711 bit stream; ESP32; USB-CUART; Emulator; client

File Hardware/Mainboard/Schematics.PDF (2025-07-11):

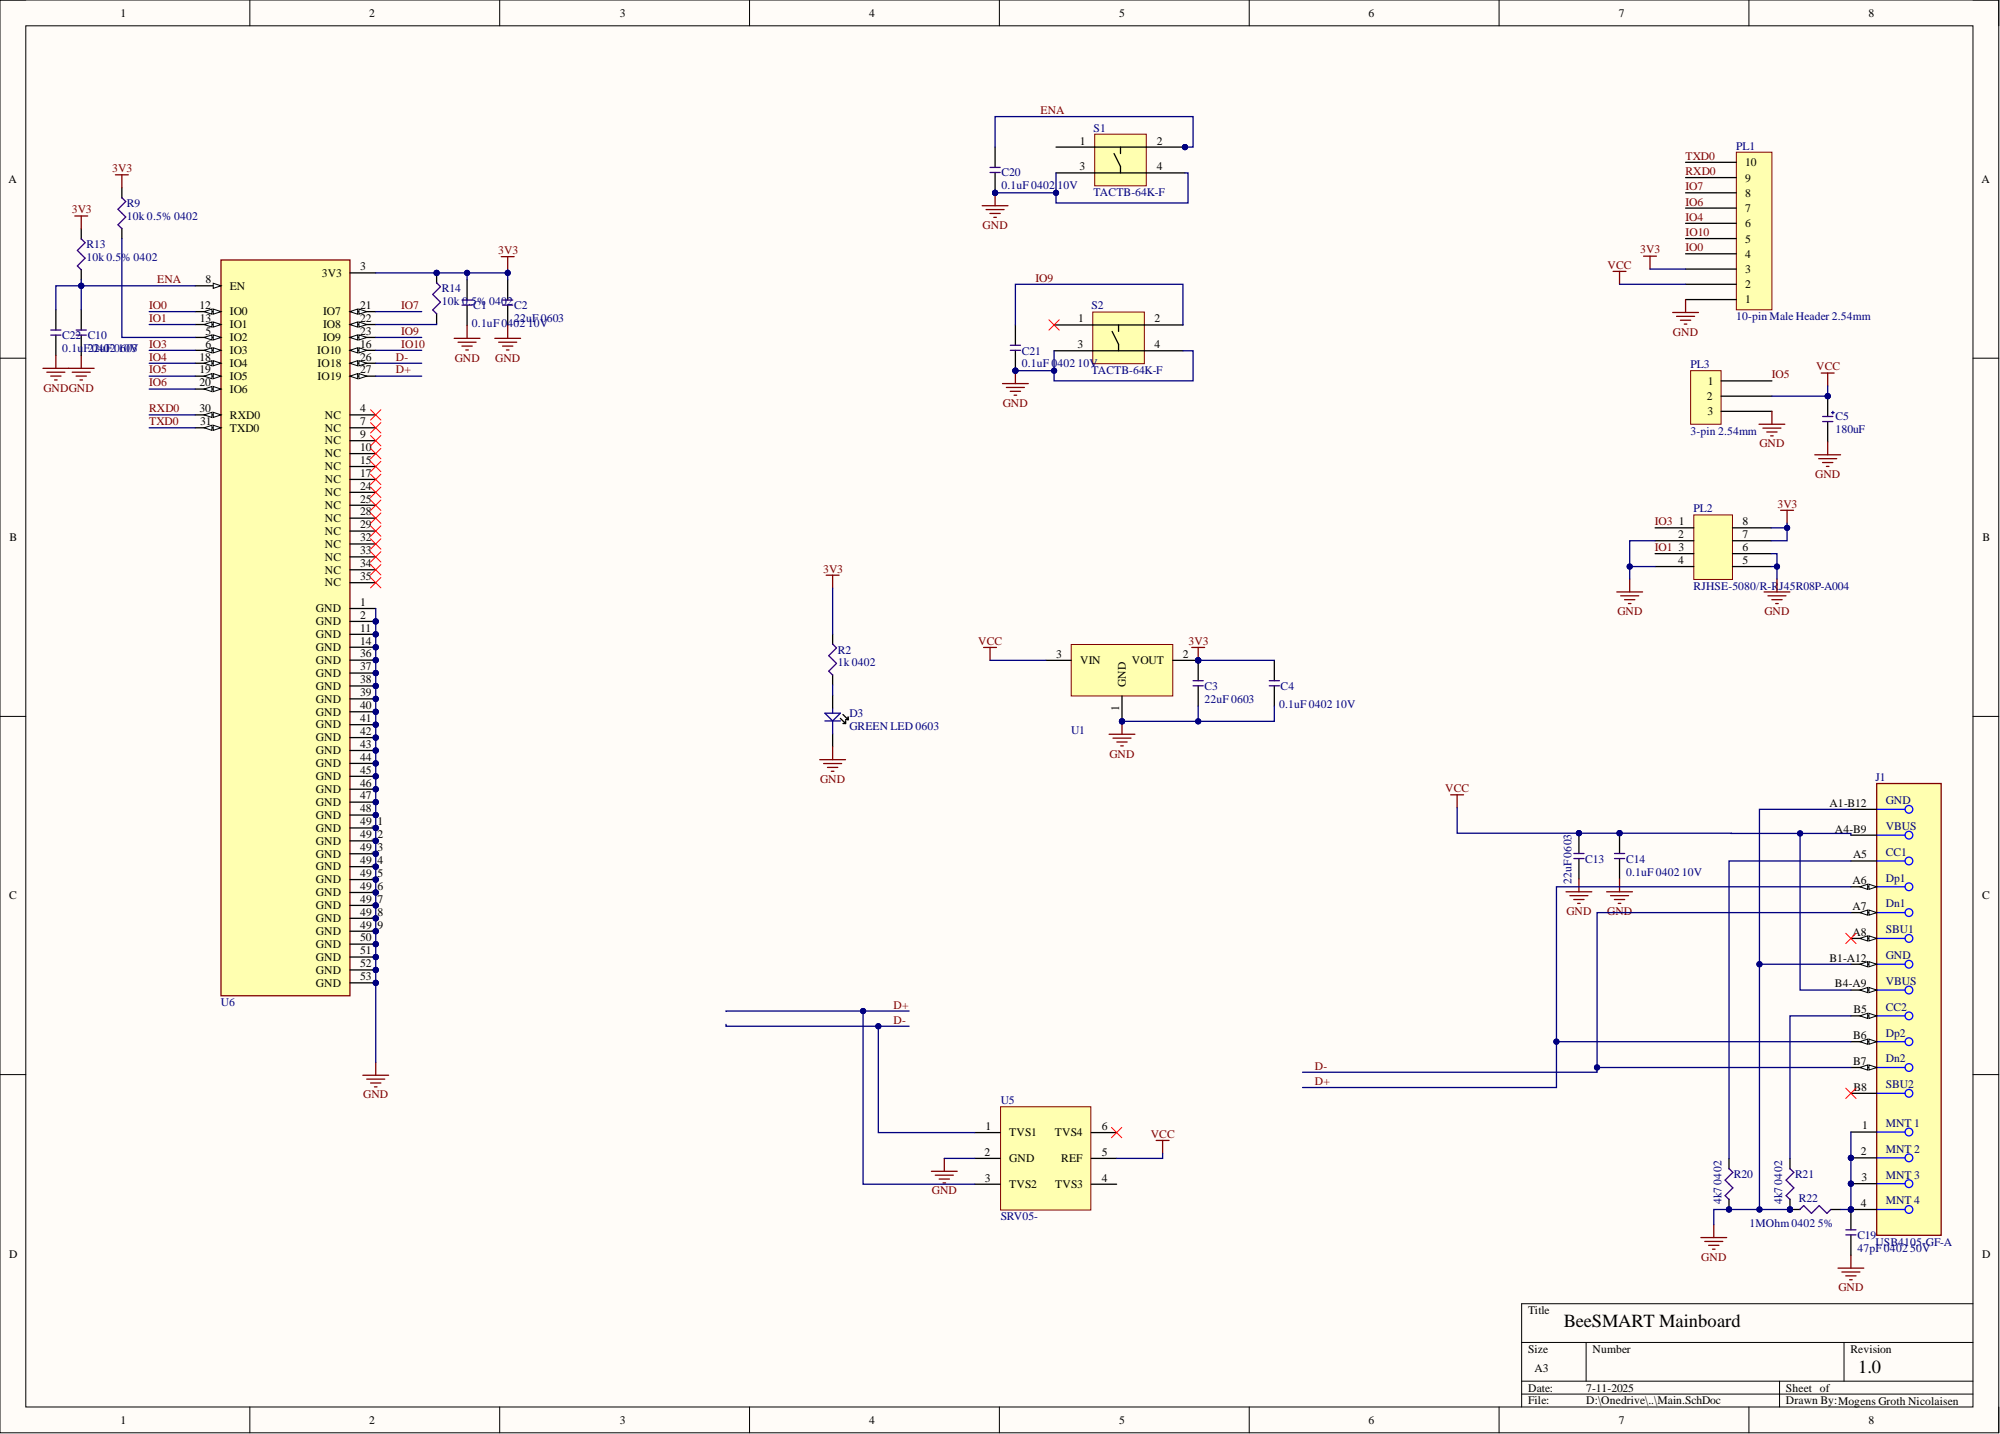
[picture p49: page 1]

13 | S2TACTB-6

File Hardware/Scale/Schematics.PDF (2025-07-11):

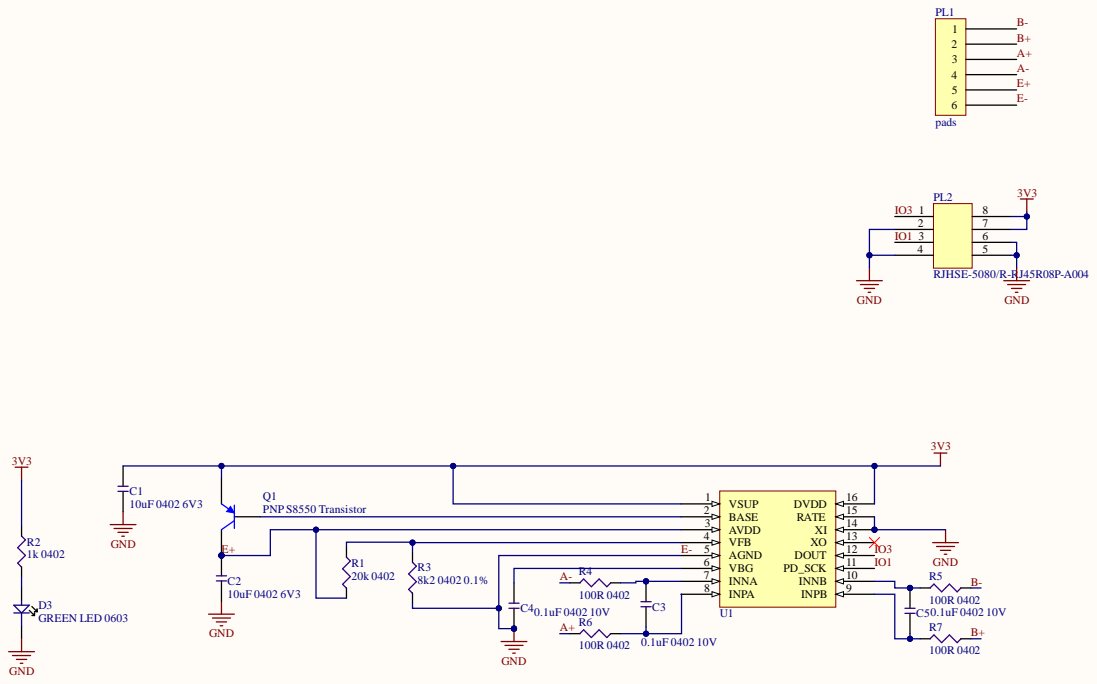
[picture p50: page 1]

IO1 3

AVDD 3

E+ | | | VFB 4
E- | AGND 5

R3 8k2 0402 0.1% | | VBG 6

R4 | INNA 7

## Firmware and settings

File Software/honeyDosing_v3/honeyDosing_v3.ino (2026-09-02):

/**
 * BeeSMART Honey Dosing System v3.3.0
 * ESP32-based precision honey dosing with PID control and web interface.
 *
 * Architecture:
 *  - honeyDosing_v3.ino: entry point (setup + loop)
 *  - src/globals.h/.cpp: global variables and language strings
 *  - src/filesystem.h/.cpp: file I/O and settings persistence
 *  - src/statistics.h/.cpp: dispensing statistics and weight sampling
 *  - src/control.h/.cpp: PID control, dosing and calibration state machines
 *  - src/webserver.h/.cpp: HTTP API, WebSocket, captive portal
 *  - config.h: constants, pin definitions, structs
 */

#include "src/config.h"
#include "src/globals.h"
#include "src/filesystem.h"
#include "src/statistics.h"
#include "src/control.h"
#include "src/webserver.h"

void setup(void) {
    Serial.begin(115200);
    Serial.println("\n" + String('\x3D', 80));
    Serial.println("BeeSMART Honey Dosing System v3.3.0 - Initializing...");
    Serial.println(String('\x3D', 80));

    if (!LittleFS.begin(FORMAT_LITTLEFS_IF_FAILED)) {
        Serial.println("CRITICAL: LittleFS Mount Failed");
        ESP.restart();
    }
    Serial.println("LittleFS file system mounted successfully");

    readCal(LittleFS, "/cal.txt");
    readFile(LittleFS, "/data.txt");
    initializeStats();
    initializeWeightSampling();

    Serial.println("Initializing hardware components...");
    scale.begin(LOADCELL_DOUT_PIN, LOADCELL_SCK_PIN);
    scale.set_scale(calFactor);
    Serial.println("Scale interface initialized with calibration factor: " + String(calFactor));

    myservo.attach(SERVO_PIN);
    Serial.println("Servo motor attached to pin " + String(SERVO_PIN));

    initPID(0.1, 1);

    WiFi.mode(WIFI_AP);
    delay(100);
    WiFi.softAPConfig(apIP, apIP, IPAddress(255, 255, 255, 0));

    uint32_t chipid = 0;
    for (int i = 0; i < 17; i = i + 8) {
        chipid |= ((ESP.getEfuseMac() >> (40 - i)) & 0xff) << i;
    }
    char ap_ssid[25];
    snprintf(ap_ssid, 26, "BeeSMART-%08X", chipid);
    WiFi.softAP(ap_ssid);

    Serial.println("WiFi AP created: " + String(ap_ssid));
    Serial.print("AP IP address: ");
    Serial.println(WiFi.softAPIP());

    dnsServer.start(DNS_PORT, "*", apIP);
    Serial.println("DNS server started for captive portal");

    initWebServer();

    webSocket.begin();
    webSocket.onEvent(webSocketEvent);
    Serial.println("WebSocket server started on port 81");

    myController.stop();
    scale.tare();
    Serial.println("Scale tared and system reset to idle state");

    Serial.println(String('\x3D', 80));
    Serial.println("BeeSMART Honey Dosing System v3.3.0 Ready!");
    Serial.println("Connect to WiFi: " + String(ap_ssid));
    Serial.println("Open browser - captive portal will redirect automatically");
    Serial.println(String('\x3D', 80) + "\n");
}

void loop(void) {
    static unsigned long lastLoopTime = 0;
    static uint8_t fullStatusCounter = 0;
    unsigned long now = millis();
    if (now - lastLoopTime >= looptime) {
        lastLoopTime = now;

        dnsServer.processNextRequest();
        server.handleClient();
        webSocket.loop();

        fullStatusCounter++;
        if (fullStatusCounter >= 50) {
            fullStatusCounter = 0;
            { String status = buildStatusJson(); webSocket.broadcastTXT(status); }
        } else if ((fullStatusCounter & 1) == 0) {
            { String weight = buildWeightUpdateJson(); webSocket.broadcastTXT(weight); }
        }

        checkAutoSave();

        actualWeight = getStableWeight();
        int16_t temp = (actualWeight - glasWeight);
        adjustedWeight = (temp < 0) ? 0 : (uint16_t)temp;

        runCalibrationStateMachine();

        runDosingStateMachine();

        if (setpoint > 0) {
            input = (float)adjustedWeight / setpoint;
        } else {
            input = 0;
        }
        if (stateMachine == 3) {
            myController.compute();
        }

        if (servoTestMode) {
            if (millis() - servoTestStartTime > 3000) {
                servoTestMode = false;
                servoTestOutput = 0.0;
            } else {
                output = servoTestOutput;
            }
        }

        myservo.write(servoMin + output * (servoMax - servoMin));
    }
}

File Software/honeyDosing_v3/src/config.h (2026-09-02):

#pragma once

#include <ArduinoJson.h>
#include <DNSServer.h>
#include <WiFi.h>
#include <WebServer.h>
#include <WebSocketsServer.h>
#include <ArduPID.h>
#include <ESP32Servo.h>
#include "HX711.h"
#include "FS.h"
#include <LittleFS.h>

#define FORMAT_LITTLEFS_IF_FAILED true

const int LOADCELL_DOUT_PIN = 3;
const int LOADCELL_SCK_PIN = 1;
const int SERVO_PIN = 5;

const byte DNS_PORT = 53;
const IPAddress apIP(192, 168, 4, 1);

const uint8_t STOP_CONFIRM_CYCLES = 3;
const uint8_t GLASS_CONFIRM_CYCLES = 10;
const uint16_t STATS_SAVE_INTERVAL = 20;
const uint8_t WEIGHT_SAMPLES = 5;
const unsigned long AUTOSAVE_DELAY = 5000;

const uint16_t maxWeightLim = 20000;

struct DispensingRecord {
  float targetWeight;
  float actualWeight;
  float error;
  unsigned long timestamp;
};

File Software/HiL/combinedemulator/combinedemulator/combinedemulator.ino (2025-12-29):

uint16_t deltaTime = 0;
uint16_t time1 = 0;
uint16_t lowVal = 545;// Ususally 1000us - Is set to 2000 for RC range calibarion procedure
uint16_t highVal = 2370;// Usually 2000us - Is set to 0 for RC range calibration procedure
const int dataPin = 3;  // Data pin connected to HX711 module
const int clockPin = 1; // Clock pin connected to HX711 module
int weight = 0;
int temp;
int indx[2];
int ii = 0;
String array;

void setup(void){
  pinMode(5,INPUT_PULLUP);    					//Hardware interrupt input on D3 with pull-up
  attachInterrupt(5, interruptRC, CHANGE);    	//Attach interrupt to the pin and react on both rising and falling edges
  pinMode(clockPin, INPUT);
  pinMode(dataPin, OUTPUT);
  digitalWrite(clockPin, HIGH); // Clock starts high
  Serial.begin(250000);
  Serial.setTimeout(1);
}

void loop() {
}

void readData() {
  // Simulate HX711 data reading process with increasing values
  /* if (Serial.available() > 0) {
    temp = Serial.parseInt();//send with no line ending via serial
    while(Serial.available())
    Serial.read();
   }*/

  while(Serial.available()){
    array = Serial.readString();
  }
  indx[0] = 0;
  for (int i = 1; i <= 1; i++) {
    indx[i] = array.indexOf(',',indx[i-1]+1);
  }
  temp = array.substring(indx[0],indx[1]).toInt();
  if(temp>=0 && temp<30000){
    weight = temp;
  }
  sendHX711Data(-250*weight);//0 to 30000g is acceptable
}

void sendServoData(){
  if(deltaTime >= lowVal*0.9 && deltaTime <= highVal*1.1){
    int16_t servoPos = map(deltaTime, lowVal, highVal, 0, 100);
    Serial.println(servoPos);
  }
}


void sendHX711Data(long data) {
  // Send data bit by bit
  digitalWrite(dataPin, LOW);
  for (int i = 23; i >= 0; i--) {
    while(digitalRead(clockPin)==LOW);
    digitalWrite(dataPin, (data >> i) & 0x01); // Shift data and send MSB first
    while(digitalRead(clockPin)==HIGH);
  }
  while(digitalRead(clockPin)==LOW);
  digitalWrite(dataPin, HIGH);
}

void interruptRC(void)
{
  if(digitalRead(5) == HIGH)// Check if input is high
  {
    time1 = micros();
  }
  else//Now it is low - calc time
  {
    deltaTime = micros()-time1;
    if(ii==2){
      sendServoData();
    }
    else if(ii==5){
      readData();
      ii=1;
    }
    ii++;
  }
}

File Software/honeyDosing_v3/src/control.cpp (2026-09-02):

#include "globals.h"
#include "control.h"
#include "filesystem.h"
#include "statistics.h"

void initPID(float lowlim, float highlim) {
    double ki = (Ti[gainSelector] > 0) ? 0.01 / Ti[gainSelector] : 0.0;
    myController.begin(&input, &output, &setpointPI,
                      kP[gainSelector] / 10,
                      ki,
                      kD[gainSelector]);

    myController.setSampleTime(looptime);
    myController.setOutputLimits(lowlim, highlim);
    myController.setWindUpLimits(0, 0.5);

    stopSystem();

    Serial.println("PID initialized with viscosity preset: " + String(gainSelector));
}

void stopSystem() {
    myController.stop();
    myController.reset();
    output = 0;
    stateMachine = 4;
    stopConditionCount = 0;

    Serial.println("SYSTEM STOPPED. Weight: " + String(adjustedWeight) + "g, Target: " + String(setpoint) + "g");
}

void runCalibrationStateMachine() {
    switch (calStateMachine) {
        case 0:
            if (LittleFS.exists("/cal.txt") == 0) {
                calStateMachine = 1;
            }
            break;

        case 1:
            break;

        case 2:
            if (!tareInProgress) {
                tareInProgress = true;
                tareStartTime = millis();
            }
            if (millis() - tareStartTime > 1000) {
                scale.set_scale();
                scale.tare();
                calStateMachine = 3;
                tareInProgress = false;
            }
            break;

        case 3:
            break;

        case 4:
            if (!calAveraging) {
                calSum = 0;
                calCount = 0;
                calAveraging = true;
            }

            calSum += scale.get_units(1);
            calCount++;

            if (calCount >= calSamples) {
                float avgReading = (float)calSum / calSamples;
                float calibFactor = avgReading / calWeight.toInt();
                writeFile(LittleFS, "/cal.txt", String(calibFactor) + ",");
                scale.set_scale(calibFactor);
                initializeWeightSampling();
                calAveraging = false;
                calStateMachine = 0;
            }
            break;

        default:
            break;
    }
}

void runDosingStateMachine() {
    switch (stateMachine) {
        case 1:
            if (actualWeight < minGlassWeight) {
                cnt = 0;
            } else {
                cnt++;
            }
            if (cnt > GLASS_CONFIRM_CYCLES) {
                glasWeight = actualWeight;
                cnt = 0;
                stateMachine = 2;
            }
            break;

        case 2:
            if (actualWeight < minGlassWeight) {
                stateMachine = 4;
                break;
            }
            setpoint = max(1.0, (double)desiredAmount.toInt());
            setpointPI = 1.0;
            myController.start();
            stateMachine = 3;
            break;

        case 3:
            if (actualWeight < minGlassWeight) {
                stopSystem();
                break;
            }
            if (setpoint - adjustedWeight < stopHysteresis) {
                stopConditionCount++;
                if (stopConditionCount >= STOP_CONFIRM_CYCLES) {
                    myController.stop();
                    myController.reset();
                    output = 0;
                    stateMachine = 4;
                    stopConditionCount = 0;
                    spikeDetected = false;
                    preSpikeWeight = 0;
                    recordWeight = adjustedWeight;
                    Serial.println("Dosing completed - target weight reached");
                }
            } else {
                stopConditionCount = 0;
            }
            break;

        case 4:
            myController.stop();
            myController.reset();

            if (setpoint > 0) {
                if (adjustedWeight > recordWeight) {
                    uint16_t delta = adjustedWeight - recordWeight;
                    if (delta > recordWeight / 20) {
                        if (!spikeDetected) {
                            spikeDetected = true;
                            preSpikeWeight = recordWeight;
                        }
                    } else {
                        recordWeight = adjustedWeight;
                    }
                }
            }

            if (actualWeight < minGlassWeight) {
                if (setpoint > 0) {
                    uint16_t finalWeight = spikeDetected ? preSpikeWeight : recordWeight;
                    recordDispensingStats(finalWeight);
                    setpoint = 0;
                }
                if (autoState == 1) {
                    stateMachine = 1;
                    cnt = 0;
                }
            }
            break;

        default:
            break;
    }
}

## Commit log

2025-02-17 added 3D files
    [Bracket.stl, Button.stl, Controller.stl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]
2025-07-11 added hardware, software and new STLs
    [40mm.stl, beesmart_scale.step, rev2_40mm.stl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]
2025-07-28 added mechanical source file
    [40mm.stl, Bracket.stl, Button.stl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]
2025-07-28 readme update
    [Bracket_40mm.stl, Bracket_53mm.stl, Button.stl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]
2025-08-02 source and production files added
    [BOM1.xlsx, PickAndPlace1.xls]
2025-10-10 minor fix on servo test
    [honeyDosing_v3.ino]
2025-12-28 rev 3 update w. new mechanical and update on HW
    [40mm btm insert.stl, 40mm top insert.stl, 53mm btm bracket.stl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]
2026-03-28 v3.2.0: Bug fixes, features, and code cleanup
    Bug fixes:
    - Number input fields no longer revert while typing (focus guard)
    - Slider snap-back fixed (skip stale poll updates during debounce)
    - Ti=0 division by zero in PID controller
    - CSV parsing bug corrupting kP for presets 1-3
    - Division by zero when setpoint=0 (idle state)
    - API input validation (gainSelector, lang, calWeight, servo, amount, etc.)
    - snprintf buffer overflow in WiFi SSID formatting
    - Hardcoded Danish string in calibration step 2
    - Settings polling interval leak (setInterval not cleared)
    - setpointPI normalisation bug
    - Button icons destroyed by updateLanguage() (data-key moved to inner spans)
    - Start blocked during active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
    [app.js, honeyDosing_v3.ino]
2026-06-08 Add core functionality for honey dosing system
    - Introduced configuration header (config.h) for defining constants and settings.
    - Implemented control logic in control.cpp and control.h for PID initialization, system stopping, and state machine management for calibration and dosing.
    - Developed filesystem handling in filesystem.cpp and filesystem.h for reading and writing settings and calibration data.
    - Created global variables and structures in globals.cpp and globals.h to manage system state and parameters.
    - Added statistics tracking in statistics.cpp and statistics.h for recording dispensing data and calculating averages.
    - Built web server functionality in webserver.cpp and webserver.h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
2026-06-08 Reset autoState when stopping the system and update stop message format
    [control.cpp, webserver.cpp]
2026-06-09 added flasher tool and guide
    [Servo_arm.stl, Servoarm.stl]

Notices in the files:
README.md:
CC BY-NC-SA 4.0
